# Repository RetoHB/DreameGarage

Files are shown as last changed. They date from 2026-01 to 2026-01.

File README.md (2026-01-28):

# Dreame robot vacuum automatic garage door
## Introduction
A WiFi-connected garage door controller that automatically opens and closes a garage door based on the state of a Dreame Master robot vacuum, using Home Assistant, Adafruit IO as a cloud bridge and an ESP32-class microcontroller for real-time motor control.
## General Description
The system uses an ESP-based microcontroller to control a DC motor through an L298N H-bridge. Motor movement is handled using a non-blocking state machine with controlled acceleration and deceleration, ensuring smooth and predictable motion.
On startup, the controller performs an automatic calibration cycle using a limit switch to establish a known reference position. This allows the door to recover correctly after resets or power interruptions.
The controller periodically reads the Dreame vacuum state from Adafruit IO, which is updated by Home Assistant. Based on this state, the door opens when the vacuum starts cleaning and closes when it returns to its base or enters charging mode.

A lightweight HTTP web interface provides local control and status monitoring. A hardware watchdog is used to automatically reset the controller if the main loop stalls, ensuring continued operation without user intervention.

The Dreame robot’s Master base is positioned lower than the surrounding floor level. To allow the robot to leave the base and return for reliable docking, an additional **ramp** is required. The ramp geometry ensures that the robot’s front wheel lowers early enough to achieve the correct docking angle.
The required 3D-print files for the ramp are included in this repository.
## System Overview
### Control Flow
`Home Assistant → Adafruit IO → ESP Controller → L298N → DC Motor → Garage Door`
### Hardware components
- Electric tailgate trunk strut, pulleys and steel cable
- Xiao ESP32C3
- Joy-IT MotorDriver2
- Limit switch e.g. D2F-01L3
- 12V power supply
- Two drawer slides, shortened
### Wiring
Dreame garage door schematic
<br>
<br>

## Video and photos
### Video
Watch the video (https://youtu.be/4hi8PueUa7Y)
<br>

<br>

Dreame garage door controller&nbsp;&nbsp;&nbsp;&nbsp;&nbsp;
Dreame garage door internal view

<video src="https://youtu.be/4hi8PueUa7Y" width=500/>

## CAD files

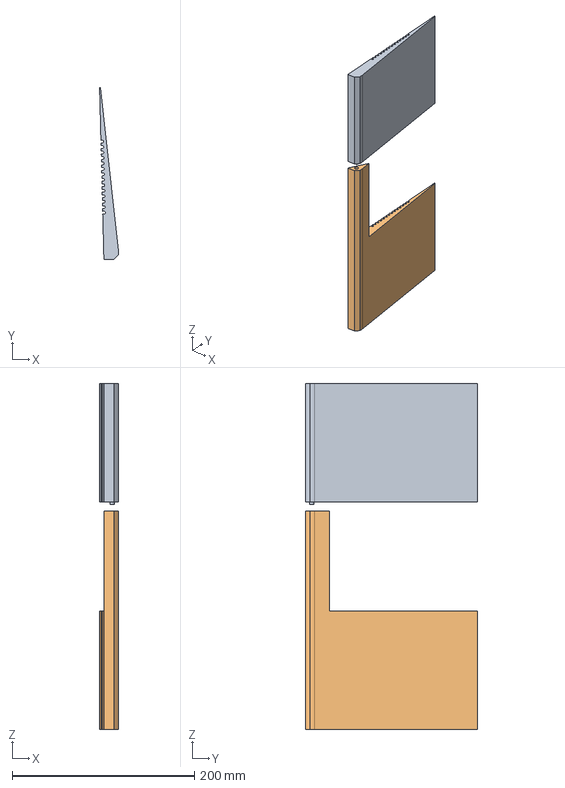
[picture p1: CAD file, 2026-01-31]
Dreame ramp.stp
20.7 x 188.9 x 380.0 mm

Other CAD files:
Dreame ramp.stl

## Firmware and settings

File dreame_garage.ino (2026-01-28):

  /*************************************************************

   Dreame Garage Door v1.3
   Reto Huber
   2026
   for Xiao ESP32C3 controller
   
 *************************************************************/

#include <WiFi.h>
#include <HTTPClient.h>
#include <ESPAsyncWebServer.h>
#include <AsyncTCP.h>
#include <ArduinoJson.h>
#include <ArduinoOTA.h>
#include <esp_task_wdt.h>
#include <time.h>

#define WIFI_SSID       "mySSID"
#define WIFI_PASS       "myPass"
#define IO_USERNAME     "myUsername"
#define IO_KEY          "myKey"
#define FEED_KEY        "dreame-status";

#define limitSwitch D4
#define LED1        D5
#define LED2        D6

#define PWM_PIN D8     // PWM output to L298N ENA
#define IN1     D9     // Input1 to L298N
#define IN2    D10     // Input2 to L298N

const unsigned long accelMotorTime = 1000;     // constant for time motor accelerates and decelerates
unsigned long fullSpeedMotorTime = 0;       // global variable for time motor runs at full speed
const unsigned long fullSpeedUpTime = 1850;    // constant for time motor runs up
const unsigned long fullSpeedDownTime = 2100;  // constant for time motor runs down
int maxPWM = 0;                              // global variable for maximum speed
const int maxPWMup = 160;                      // constant for maximum speed up
const int maxPWMdown = 120;                    // constant for maximum speed down
int pwmValue = 0;                              // global variable for current speed
unsigned long stateStartTime = 0;              // timing variable for motor motion phases (IDLE, ACCEL, FULLSPEED, DECEL)
bool watchdogNightMode = false;                // track current watchdog mode

bool openDoor = false;      // door action to perform
bool lastOpenDoor = false;  // last door action
bool creepDone = false;

// ---------------- LED Blink Variables ----------------
bool LEDstate = LOW;
unsigned long lastBlink = 0;
const unsigned long BLINK_INTERVAL = 200;  // ms

// ------------ Adafruit IO poll variables -------------
unsigned long lastPoll = 0;                   // time of last poll to Adafruit IO
const unsigned long POLL_INTERVAL = 2000;     // interval in ms to poll Adafruit IO
String dreame_state = "";                     // current state of Dreame
String dreame_status = "";                    // current status of Dreame
String dreame_room = "";                      // current room Dreame is in
String dreame_task = "";                      // current task of Dreama
String last_dreame_state = "";                // last state of Dreame
String last_dreame_status = "";               // last status of Dreame
String last_dreame_room = "";                 // last room Dreame was in
String last_dreame_task = "";                 // last task of Dreame
bool updatedData = false;                     // Flag to indicate new data arrived
int lastAIOerror = 0;
unsigned long lastIOupdate = 0;               // time of last update from Adafruit IO
unsigned long timeBetweenUpdates = 0;         // time between Adafruit IO updates
struct tm lastResetTime;                      // last time controller was booted

// -------------------- Web Server ---------------------
AsyncWebServer server(80);

void setupTime();
void configureWatchdog();
void updateWatchdogByTime();
void pollAdafruitIO();
String buildPage();
void evaluateState();
void updateDoor();
void startCalibration();
void startOpening();
void startClosing();
bool limitReached();
void handleMotorSequence();
void updateLED();
void setLEDs();

// ----------- State machine for door state -----------
enum DoorState {
  DOOR_IDLE,
  DOOR_CALIBRATING,
  DOOR_OPENING,
  DOOR_CLOSING
};
DoorState doorState = DOOR_IDLE;

// -------- State machine for motion phases ----------

enum MotionState {
  IDLE,
  ACCEL,
  FULLSPEED,
  DECEL
};
MotionState motionState = IDLE;

// ============================================================
// setup() function
// ============================================================

void setup()
{
  pinMode(limitSwitch, INPUT_PULLUP);
  
  pinMode(LED1, OUTPUT);
  pinMode(LED2, OUTPUT);
  digitalWrite(LED1, LOW);
  digitalWrite(LED2, LOW);

  pinMode(IN1, OUTPUT);
  pinMode(IN2, OUTPUT);
  digitalWrite(IN1, LOW);
  digitalWrite(IN2, LOW);
  pinMode(PWM_PIN, OUTPUT);
  analogWrite(PWM_PIN, 0);
  
  Serial.begin(115200);
  delay(1000);
  Serial.println("\nDreame Garage Door controller");
  Serial.println("*****************************");
  Serial.println("\nConnecting to WiFi...");

  // ------------- WiFi connection ---------------

  WiFi.begin(WIFI_SSID, WIFI_PASS);
  while (WiFi.status() != WL_CONNECTED) {
    delay(500);
    Serial.print(".");
  }
  Serial.println("\nWiFi connected!");
  Serial.print("IP address:\t");
  IPAddress myIP = WiFi.localIP();
  Serial.println(myIP);

  // ---------------- OTA updates ----------------

  ArduinoOTA.setHostname("Dreame Garage Door");   // optional, shows in IDE

  ArduinoOTA.onStart([]() {
    esp_task_wdt_delete(NULL);
    Serial.println("Watchdog disabled for OTA");
    Serial.println("Start OTA update");
  });
  ArduinoOTA.onEnd([]() {
    Serial.println("\nEnd OTA update");
    esp_task_wdt_add(NULL);
    Serial.println("Watchdog re-enabled after OTA");
  });
  ArduinoOTA.onProgress([](unsigned int progress, unsigned int total) {
    Serial.printf("Progress: %u%%\r", (progress / (total / 100)));
  });
  ArduinoOTA.onError([](ota_error_t error) {
    Serial.printf("Error[%u]: ", error);
    if (error == OTA_AUTH_ERROR) Serial.println("Auth Failed");
    else if (error == OTA_BEGIN_ERROR) Serial.println("Begin Failed");
    else if (error == OTA_CONNECT_ERROR) Serial.println("Connect Failed");
    else if (error == OTA_RECEIVE_ERROR) Serial.println("Receive Failed");
    else if (error == OTA_END_ERROR) Serial.println("End Failed");
  });
  ArduinoOTA.begin();
  Serial.println("OTA ready");

  setupTime();

  // ---------- Setup handlers for Webserver ------------

  // --------- "root page" offering the command links -----------
    
  server.on("/", HTTP_GET, [](AsyncWebServerRequest *request) {
    request->send(200, "text/html",
                  buildPage("Dreame Garage Door Controller", ""));
  });

  // ------------------ "open command" page ---------------------

  server.on("/open", HTTP_GET, [](AsyncWebServerRequest *request) {
    openDoor = true;
    request->send(200, "text/html",
                  buildPage("Dreame Garage Door Controller", "Door <b>opening</b> command received."));
  });

  // ----------------- "close command" page ---------------------

  server.on("/close", HTTP_GET, [](AsyncWebServerRequest *request) {
    openDoor = false;
    request->send(200, "text/html",
                  buildPage("Dreame Garage Door Controller", "Door <b>closing</b> command received."));
  });

  // --------------------- "status" page ------------------------

  server.on("/status", HTTP_GET, [](AsyncWebServerRequest *request) {
    String status;
    switch (doorState) {
      case DOOR_IDLE:        status = "Idle"; break;
      case DOOR_CALIBRATING: status = "Calibrating"; break;
      case DOOR_OPENING:     status = "Opening"; break;
      case DOOR_CLOSING:     status = "Closing"; break;
    }

    struct tm timeinfo;
    char buf1[32];
    char buf2[32];
    getLocalTime(&timeinfo);
    strftime(buf1, sizeof(buf1), "%H:%M", &timeinfo);
    strftime(buf2, sizeof(buf2), "%H:%M", &lastResetTime);

    String body = "Door is currently: " + status + "<br>Last state was: " + dreame_status + "<br>Current room is: " + dreame_room + "<br>Current task is: " + dreame_task + "<br> ESP reset reason: " + esp_reset_reason() + "<br>Last reset time: " + String(buf2) + "<br>Last AdafruitIO error: " + lastAIOerror + "<br> Time between AIO updates (ms): " + timeBetweenUpdates + "<br>Current time: " + String(buf1) +"<br>";

    request->send(200, "text/html",
                  buildPage("Dreame Garage Door Controller", body));
    });               

  server.begin();
  Serial.println("HTTP server started.");
   

  // ----------------- Start door calibration ---------------------

  startCalibration();
}

// ============================================================
// main loop()
// ============================================================

void loop()
{  
  // ---------- Reconnect to WiFi if connection lost ------------
    
  if (WiFi.status() != WL_CONNECTED) {
    Serial.println("WiFi disconnected, reconnecting...");
    setLEDs(HIGH);
    WiFi.reconnect();
    delay(5000);
    return;
  }

  // ------------- Timer to poll AdafruitIO value ---------------
  
  unsigned long currentMillis = millis();
  if (currentMillis - lastPoll >= POLL_INTERVAL) {
    if (doorState == DOOR_IDLE) {
      lastPoll = currentMillis;
      pollAdafruitIO();
      evaluateState();
    }
    updateWatchdogByTime(); // update watchdog periodically
  }
  
  updateDoor();            // Command the door
  updateLED();             // Command the LEDs
  ArduinoOTA.handle();     // Handle OTA
  esp_task_wdt_reset();    // reset watchdog
}

// ============================================================
// Function: setupTime()
// Setup NTP time
// ============================================================

 void setupTime() {
    configTime(0, 0, "pool.ntp.org", "time.nist.gov");
    
    // Central European Time with automatic DST
    setenv("TZ", "CET-1CEST,M3.5.0/2,M10.5.0/3", 1);
    tzset();
  
    Serial.println("Waiting for NTP time sync...");
    struct tm timeinfo;
    while (true) {
      if (getLocalTime(&timeinfo)) {
        if (timeinfo.tm_year > (2025 - 1900)) break;  // real time arrived
      }
      Serial.print(".");
      delay(500);
    }
    delay(5000);
    Serial.println("\nTime synchronized");
    getLocalTime(&lastResetTime);
 }

// ============================================================
// Function: configureWatchdog(uint32_t timeoutSeconds)
// helper to reconfigure watchdog safely
// ============================================================

void configureWatchdog(uint32_t timeoutSeconds) {
  esp_task_wdt_delete(NULL);          // remove current task
  esp_task_wdt_deinit();              // stop watchdog
  esp_task_wdt_init(timeoutSeconds, true);  // restart with new timeout
  esp_task_wdt_add(NULL);             // re-add loop task

  Serial.print("Watchdog timeout set to ");
  Serial.print(timeoutSeconds);
  Serial.println(" seconds");
}

// ============================================================
// Function: updateWatchdogByTime()
// switch watchdog automatically based on time
// ============================================================

void updateWatchdogByTime() {
  struct tm timeinfo;
  if (!getLocalTime(&timeinfo)) return;

  int hour = timeinfo.tm_hour;

  bool nightNow = (hour >= 20 || hour < 8);

  if (nightNow != watchdogNightMode) {
    watchdogNightMode = nightNow;

    if (nightNow)
      configureWatchdog(3600);
    else
      configureWatchdog(60);
  }
}

// ============================================================
// Function: runMotorSequence(direction, fullSpeedTime, maxPWMValue)
// Call once to start the sequence; it runs non-blocking.
// ============================================================

void runMotorSequence(String direction, unsigned long fullSpeedTime, int maxPWMValue) {
  if (motionState != IDLE) return;     // motor already running

  fullSpeedMotorTime = fullSpeedTime;  // update global duration
  maxPWM = maxPWMValue;                // update global max PWM
  stateStartTime = millis();           // start time of current motion phase
  motionState = ACCEL;

  // Set motor direction
  if (direction == "down") {
    digitalWrite(IN1, HIGH);
    digitalWrite(IN2, LOW);
  } else if (direction == "up") {
    digitalWrite(IN1, LOW);
    digitalWrite(IN2, HIGH);
  }
}

// ============================================================
// Function: handleMotorSequence()
// Non-blocking motor control handler, call this continuously inside loop()
// ============================================================

void handleMotorSequence() {
  unsigned long currentTime = millis();
  unsigned long elapsed = currentTime - stateStartTime;   // time current motion phase is already running

  switch (motionState) {
    // in IDLE deactivate motor controller
    case IDLE:
      analogWrite(PWM_PIN, 0);
      digitalWrite(IN1, LOW);
      digitalWrite(IN2, LOW);
      return;

    case ACCEL:
    // in ACCEL steadily increase PWM value while motor acceleration time is not up
      if (elapsed <= accelMotorTime) {
        pwmValue = map(elapsed, 0, accelMotorTime, 0, maxPWM);   // map(value, fromLow, fromHigh, toLow, toHigh)
      } else {                                                   // when time is up change to FULLSPEED
        pwmValue = maxPWM;
        motionState = FULLSPEED;
        stateStartTime = currentTime;
      }
      break;

    case FULLSPEED:
    // in FULLSPEED run motor at maximum PWM
      pwmValue = maxPWM;
      if (elapsed >= fullSpeedMotorTime) {   // when time is up change to DECEL
        motionState = DECEL;
        stateStartTime = currentTime;
      }
      break;

    case DECEL:
    // in DECEL steadily lower PWM value while motor deceleration time is not up
      if (elapsed <= accelMotorTime) {
        pwmValue = map(elapsed, 0, accelMotorTime, maxPWM, 0);   // map(value, fromLow, fromHigh, toLow, toHigh)
      } else {                                                   // when time is up change to FULLSPEED
        pwmValue = 0;
        motionState = IDLE;
      }
      break;
  }

  analogWrite(PWM_PIN, pwmValue);   // continously write the current PWM value to the output pin
}

// ============================================================
// Function: updateDoor()
// Move the door
// ============================================================

void updateDoor() {
  handleMotorSequence();                // handle the motor continously

  switch (doorState) {
    case DOOR_CALIBRATING:
      if (limitReached()) {             // limit switch has triggered
        pwmValue = 0;                   // stop the motor
        Serial.println("Calibration complete. Limit switch triggered.");
        doorState = DOOR_IDLE;          // door is IDLE now
        motionState = IDLE;             // ensure motor sequence fully stops
        startClosing();                 // close the door after calibration
      }
      break;

      case DOOR_OPENING:
        if (limitReached()) {            // limit switch has triggered
          analogWrite(PWM_PIN, 0);       // stop the motor
          digitalWrite(IN1, LOW);
          digitalWrite(IN2, LOW);
          Serial.println("Door fully open (limit switch triggered)");
          doorState = DOOR_IDLE;         // door is IDLE now
          motionState = IDLE;            // ensure motor sequence fully stops
          creepDone = false;             // reset for next cycle
        } 
        else if (motionState == IDLE && !creepDone) {  // motor stopped because runtime is up, but door is not at limit
          Serial.println("Top not reached, creeping slowly upward...");
          creepDone = true;                  // only once!
          setLEDs(HIGH);
          runMotorSequence("up", 2000, 100); // reposition gently
        }
        break;

    case DOOR_CLOSING:
      if (motionState == IDLE) {
        Serial.println("Door fully closed.");
        doorState = DOOR_IDLE;
      }
      break;

    case DOOR_IDLE:
      if (openDoor != lastOpenDoor) {   // check if openDoor command has changed
      lastOpenDoor = openDoor;          // set the new openDoor command as lastOpenDoor command
        if (openDoor) startOpening();
        else startClosing();
      }
      break;
    }
}

// ============================================================
// Functions to change state of state machine and command the motor
// ============================================================
  
void startCalibration() {
  Serial.println("Calibrating: moving up until limit switch...");
  doorState = DOOR_CALIBRATING;
  creepDone = false;
  runMotorSequence("up", 8000, 100); // slower calibration
}

void startOpening() {
  Serial.println("Opening door...");
  doorState = DOOR_OPENING;
  openDoor = true;
  runMotorSequence("up", fullSpeedUpTime, maxPWMup);
}

void startClosing() {
  Serial.println("Closing door...");
  doorState = DOOR_CLOSING;
  openDoor = false;
  creepDone = false;
  runMotorSequence("down", fullSpeedDownTime, maxPWMdown);
}

// ============================================================
// Function: limitReached()
// Check if limitSwitch has triggered
// ============================================================

bool limitReached() {
  return digitalRead(limitSwitch) == LOW;  // invert if sensor active HIGH
}

// ============================================================
// Function: setLEDs()
// Change LED state with one command
// ============================================================

void setLEDs(bool state) {
  digitalWrite(LED1, state);
  digitalWrite(LED2, state);
}

// ============================================================
// Function: updateLED()
// control LEDs depending on door state
// ============================================================

void updateLED() {
  unsigned long now = millis();
  bool moving = (doorState == DOOR_CALIBRATING ||   // if doorState is one of these values, door is moving
                 doorState == DOOR_OPENING ||
                 doorState == DOOR_CLOSING);

  if (moving) {   // if the door is moving LEDs blink
    if (now - lastBlink >= BLINK_INTERVAL) {
      lastBlink = now;
      LEDstate = !LEDstate;
      setLEDs(LEDstate);
    }
  } else {   // Else, solid ON when open, OFF when closed
    if (doorState == DOOR_IDLE && openDoor)
      setLEDs(HIGH);
    else
      setLEDs(LOW);
  }
}

// ============================================================
// HTML page builder
// ============================================================

// ---- setting up a formatted page to deliver the message ----

String buildPage(String title, String body) {
  return
    "<html><head>"
    "<meta name='viewport' content='width=device-width, initial-scale=1.0'>"
    "</head><body>"
    "<h2>" + title + "</h2>"
    "<p>" + body + "</p>"
    "<p><a href=\"/open\">Open Door</a></p>"
    "<p><a href=\"/close\">Close Door</a></p>"
    "<p><a href=\"/status\">Check Status</a></p>"
    "</body></html>";
}

// ============================================================
// Function: pollAdafruitIO()()
// get current values of Dreame from AdafruitIO
// ============================================================

void pollAdafruitIO() {
  bool changed = false;

  HTTPClient http;
  String url = "https://io.adafruit.com/api/v2/";
  url += IO_USERNAME;
  url += "/groups/";
  url += AIO_GROUP_KEY;
  url += "/feeds";

  http.begin(url);
  http.addHeader("X-AIO-Key", IO_KEY);

  int httpCode = http.GET();
  if (httpCode != HTTP_CODE_OK) {
    lastAIOerror = httpCode;
    http.end();
    return;
  }

  StaticJsonDocument<2048> doc;
  DeserializationError err = deserializeJson(doc, http.getString());
  http.end();

  if (err) {
    lastAIOerror = -1;   // JSON error
    return;
  }

  for (JsonObject feed : doc.as<JsonArray>()) {
    if (feed["last_value"].isNull()) continue;

    String key   = feed["key"].as<String>();
    String value = feed["last_value"].as<String>();

    if (key == "dreame-state") {
      timeBetweenUpdates = millis() - lastIOupdate;
      lastIOupdate = millis();
      if (value != last_dreame_state) {
        last_dreame_state = value;
        dreame_state = value;
        changed = true;
      }
    }
    else if (key == "dreame-status") {
      if (value != last_dreame_status) {
        last_dreame_status = value;
        dreame_status = value;
        changed = true;
      }
    }
    else if (key == "dreame-room") {
      if (value != last_dreame_room) {
        last_dreame_room = value;
        dreame_room = value;
        changed = true;
      }
    }
    else if (key == "dreame-task") {
      if (value != last_dreame_task) {
        last_dreame_task = value;
        dreame_task = value;
        changed = true;
      }
    }
  }

  updatedData = changed;
}

// ============================================================
// Function: evaluateState()
// Evaluate Dreame status and take door action
// ============================================================

void evaluateState() {
  if (!updatedData) return;
  updatedData = false;
  
  if (dreame_room != "Kitchen") {
    Serial.println("Dreame not in Kitchen → close");
    openDoor = false;
    return;
  }  

  if (dreame_state == "auto_emptying") {
    Serial.println("Dreame auto-emptying → close");
    openDoor = false;
    return;
  }

  if (((dreame_status == "charging") ||
       (dreame_status == "idle") ||
       (dreame_status == "standby") ||
       (dreame_status == "sleeping") ||
       (dreame_status == "unavailable")) &&
       (dreame_task != "cleaning")) {
    Serial.println("Dreame is docked and task completed → close");
    openDoor = false;
  }
  else {
    Serial.println("Dreame is in Kitchen and still working → open");
    openDoor = true;
  }
}

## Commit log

2026-01-18 Rename Dreame Rampe.stl to Dreame ramp.stl
    [Dreame ramp.stl]
2026-01-18 Update and rename Dreame Rampe.stp to Dreame ramp.stp
    [Dreame ramp.stp]
